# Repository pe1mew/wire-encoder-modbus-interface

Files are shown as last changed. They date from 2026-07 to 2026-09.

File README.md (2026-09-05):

# Wire Encoder Modbus Interface

A CH32V003-based interface board that measures **how far a window is open**
and publishes it on **Modbus RTU over RS-485**, powered by 24 V passive PoE
and designed for daisy-chained field buses.

The measurement comes from a **draw-wire encoder**: a spring-loaded drum
pays out a steel wire attached to the moving window frame, and the drum
turns a **10 kΩ potentiometer**. The wiper voltage is therefore an absolute
measure of the opening — valid the instant power returns, with no homing
move and no count to lose.

Two end-of-travel switches report that the window has reached a mechanical
stop, read as a supervised resistor ladder that also monitors its own cable.

One firmware build, addressed by a PC1 solder jumper:

| Jumper open | Jumper bridged |
|---|---|
| **40** | 45 |

The 40/45 pair is deliberately clear of the sibling
[`windmeters-modbus-interface`](https://github.com/pe1mew/windmeters-modbus-interface)
family (30–37), so both can share one RS-485 segment.

## Project status (2026-09-05)

| Area | State |
|---|---|
| Requirements | [`design/TDS.md`](design/TDS.md) **v0.7** — **79 requirements** (28 FR-MB, 20 FR-S, 23 FR-E, 8 NFR), every one traced to a test row and **gate-enforced** by `software/hil/acceptance/test_traceability.py` |
| Drivers | Modbus RTU + debug UART carried over HIL-verified; the encoder driver (`software/drivers/wire_encoder/`) is **written, verified and integrated** |
| Product firmware | **Complete.** Integration stages **A–F done** ([`design/integrationPlan.md`](design/integrationPlan.md)) — measurement, averaging, persistence and sensing health. 6 364 B flash (44 %), 1 108 B RAM (62 %). A healthy device reports status `0x0000` |
| Hardware/HIL | Schematic and PCB layout in `hardware/KiCad/`; the build under test is still a **breadboard**, so every Group A result carries that caveat. HIL rig complete: ADALM2000 RS-485 master, Saleae Logic16, and a built window emulator |
| Testing | 3 host suites (`scale`, `avg`, `health`), 27 HIL scripts, 11 acceptance tests. Results in [`software/hil/testReport.md`](software/hil/testReport.md) |
| Blocked | Four items, all on **instruments, not code**: adjustable PSU (±15 % supply margin, TP-A03/TP-B23 — the tightest unmeasured number), a PCB (TP-B36), a precision resistance box (FR-E03), a 5 ms bounce injector (FR-E15) |
| Release | No firmware version tagged yet; `fw-v1` is a candidate pending the above ([`software/firmware/RELEASES.md`](software/firmware/RELEASES.md)) |

## Hardware

The board reuses the sibling project's design wholesale apart from the
sensor front-end:

- **MCU**: WCH CH32V003J4M6 (RISC-V, SOP-8, 16 KB flash / 2 KB RAM). The
  8-pin package drives the whole design: single-wire UART discipline, remap
  tricks, and a zero-interrupt firmware architecture
  ([`design/softwareArchitecture.md`](design/softwareArchitecture.md)).
- **RS-485**: MAX3485; DI+RO tied to PD6, DE+R̄Ē tied to PC2 with a 10 k
  pull-down (keeps the bus safe during reset/flashing); 120 Ω terminator
  behind a solder jumper; A/B fail-safe bias; SM712 TVS.
- **Power**: 24 V passive PoE on the spare pairs (4/5 = +, 7/8 = −) →
  DB207 bridge (polarity protection only) → HLK-K7803 buck → 3.3 V.
- **Sensor front-end**: the potentiometer wiper on PA2 (ADC ch0), read
  ratiometrically against VDD — no external reference, so supply ripple
  cancels. The end-switch ladder is on PC4 (ADC ch2).

**The pin budget is the binding constraint.** The SOP-8 package bonds
several GPIO onto shared pins (pin 1 is PD6 *and* PA1; pin 8 is PD1, PD4
*and* PD5), leaving **six physical I/O pins — and every one is committed**:
Modbus data, the wiper, DE/RE, the address jumper, the end-switch ladder,
SWIO. Note PC1 and PC4 are assigned the reverse of the obvious way: PC4
carries an ADC channel and PC1 does not, so the analog pin goes to the
switch loop and the boot-time address jumper takes the digital pin. Any
front-end idea that needs another pin does not fit. See
[`design/TDS.md`](design/TDS.md) §4.2.

## Modbus register map (summary)

12 input registers (FC04) and 6 holding registers (FC03/06/16). Inputs:
instantaneous and averaged opening, the minimum/maximum of the current
averaging window, the raw ADC code, status bits (including end-of-travel
reached and switch-loop fault), identification (build + firmware version),
uptime, CRC/served counters, seconds-since-last-valid-reading, and movement
rate. Holdings: zero offset,
measurement window, averaging window, full travel, and the two-point raw
calibration (raw code closed / raw code fully open) — so one image serves
any window, calibrated in the field over Modbus. All persisted in flash
across reset/power-loss; the defaults apply only on first boot / erased
store. The authoritative map with ranges, defaults and requirement IDs is
[`design/TDS.md`](design/TDS.md) §2.7/§2.8.

## Repository layout

| Path | Contents |
|---|---|
| [`design/`](design/README.md) | The design-document chain (index in [`design/README.md`](design/README.md)): scratchBook → description → TDS → softwareArchitecture (+ UML diagrams in `design/diagrams/`) → driverDevelopment → integrationPlan |
| `hardware/KiCad/` | Schematic + PCB (KiCad); symbol libraries as git submodules |
| `hardware/Documentation/` | Component datasheets (HLK-K78xx, DB20x, MAX3483/85, Kradex enclosure) |
| `software/firmware/` | Product firmware (PlatformIO + ch32v003fun): one release build, plus a bench-only test build |
| `software/drivers/` | Standalone driver projects with HIL test shells (the verified libraries the product references in place) |
| `software/hil/` | Scripted hardware-in-the-loop harness: Saleae Logic 2 (MCP) + ADALM2000 (libm2k) + `acceptance/` pytest suite |
| `Doxyfile` | Doxygen config — builds a single site (design docs + API reference) with this README as the landing page |
| `documentation/` | Chip pinout, programmer manual, and sensor reference material |

Clone with submodules:

```sh
git clone --recurse-submodules https://github.com/pe1mew/wire-encoder-modbus-interface.git
```

## Building and flashing

Requires [PlatformIO](https://platformio.org/) and a WCH-LinkE on SWIO.

```sh
cd software/firmware
pio run                            # the release build
pio run -t upload                  # flash via WCH-LinkE
```

`encoder_test` adds bench-only hooks — never release that binary. Resource
ceilings (14 336 B flash / 1 792 B RAM, NFR-RES01) are enforced as hard
build gates.
The firmware version byte lives in `src/version.h`; the release process is
documented in `RELEASES.md`.

## Testing

- **Acceptance suite** (bench: Saleae Logic 2 with its MCP server, ADALM2000,
  WCH-LinkE, TTL Modbus rig):

  ```sh
  cd software/hil/acceptance
  ..\.venv-m2k\Scripts\python.exe -m pytest .
  ```

  Only the build-gate rows are populated so far; the protocol and
  measurement rows arrive with the driver work. See
  [`software/hil/README.md`](software/hil/README.md) for instrument setup,
  wiring, and the bench-quirk catalogue.

## Documentation

- **What the device does** — [`design/description.md`](design/description.md)
  is the functional description in prose: sensing principle, what it
  reports, commissioning, fault behaviour, and the boundary of what it does
  not do. Start there.
- **Design record** — [`design/README.md`](design/README.md) indexes the
  document chain (requirements → architecture → drivers → integration) and
  the UML diagrams.
- **API + design site** — the firmware headers/sources carry full Doxygen,
  and [`Doxyfile`](Doxyfile) folds the design docs in as pages with this
  README as the landing page. Build the browsable HTML with:

  ```sh
  doxygen Doxyfile        # output in documentation/doxygen/html/index.html
  ```

## Related repositories

- [`pe1mew/windmeters-modbus-interface`](https://github.com/pe1mew/windmeters-modbus-interface) —
  the sibling project this repository is derived from: same MCU, same
  RS-485 front-end, same zero-ISR architecture, and the same potentiometer
  reading topology. Its Modbus RTU driver, board/persistence modules and
  HIL harness are carried over here, and its `design/` chain is the
  reference for anything not yet written down.
- [`pe1mew/windmeters-modbus-interface-tester`](https://github.com/pe1mew/windmeters-modbus-interface-tester) —
  the Modbus RTU master bench tool (M5Stack AtomS3 + RS-485) used to
  exercise devices in this family.

## License

Software is provided under a Source-Available Non-Commercial License;
documentation and images under CC BY-NC-ND 4.0. See [LICENSE](LICENSE) and
[license.md](license.md). Third-party datasheets and KiCad library
submodules remain under their owners' terms.

## Author

Remko Welling (PE1MEW)

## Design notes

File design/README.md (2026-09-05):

# Design documentation

This directory holds the design record for the Wire Encoder Modbus
Interface firmware — the chain from first idea to a validated,
requirement-traced implementation. The documents build on each other in
this order:

```
scratchBook  →  description  →  TDS  →  softwareArchitecture  →  driverDevelopment  →  integrationPlan
(brainstorm)   (what it does)  (what   (how + diagrams)         (drivers + results)   (product fw + results)
                in prose)      must
                               be true)
```

## What the device does

Measures **how far a window is open** — a greenhouse vent, a roof light, a
louvre — and publishes it on Modbus RTU over RS-485. A draw-wire encoder
attached to the moving frame turns a **10 kΩ potentiometer**; the wiper
voltage is an absolute measure of the opening, valid the instant power
returns, with no homing move.

## Where this project stands

Read this before trusting a status line anywhere else: **the Modbus and
platform half of this project is inherited and proven; the measurement half
is a plan.** The documents below are honest about which is which, and the
distinction matters when you pick up the work.

| Document | Purpose | Status |
|---|---|---|
| [`description.md`](description.md) | **Functional description** — what the device does, in prose, for an integrator or installer: the sensing principle, what it reports, commissioning, fault behaviour, and what it deliberately does *not* do. Start here. | Current. The measurement path is implemented and verified; §3.1 documents the health bits and §8.1 the end-sensor and draw-wire installation rules |
| [`TDS.md`](TDS.md) | **Technical Design Specification** — the requirements contract (FR-MB…, FR-S…, FR-E…, NFR-…) with measurable pass/fail criteria. The single source of truth for behaviour. | **v0.7 draft.** §2 Modbus and §3.1/§3.2 lifecycle inherited from the sibling project's v0.9 and verified there; §2.7/§2.8 register map and the FR-E series are new and expected to move; §4 hardware open |
| [`softwareArchitecture.md`](softwareArchitecture.md) | **How** the requirements are met: the zero-ISR cooperative super-loop, the module split, the sizing rationale. §7 embeds the UML diagrams. | Current. All modules are in the tree and verified; §5 carries the as-built sizes and the **1.146 ms blocking budget** |
| [`driverDevelopment.md`](driverDevelopment.md) | Plan + results per standalone driver, each HIL-verified before integration. | All phases satisfied. Phase 1 (the encoder driver) is written, HIL-verified and integrated; its acceptance rows close through integration stages D–E |
| [`testPlan.md`](testPlan.md) | **Hardware test plan** — every row traced to a TDS verification clause, grouped by what the current image can actually exercise: electrical (no firmware), protocol and lifecycle, and what stays blocked until integration stage D. | **v0.3.** Groups B and C executed and passing; Group A partly blocked on an adjustable PSU and a PCB. Every requirement is gate-checked for a test row by `test_traceability.py` |
| [`integrationPlan.md`](integrationPlan.md) | The product-firmware plan: stages A–F, each with an exit criterion, plus the hardware-gated test set. | **Stages A–F all complete.** Remaining work is blocked on instruments, not code |
| [`scratchBook.md`](scratchBook.md) | The brainstorm and working notes seeding the TDS — the sensor, the pin budget, scaling derivation, resolution/range decision, hardware questions. | Working notes |
| [`windowEmulator.md`](windowEmulator.md) | **Window and window-controller emulator** — a bench rig standing in for a window and its actuator controller: the control logic and its truth table, plus the mechanical and safety requirements. Scoped to the rig alone; it specifies nothing about what is mounted on it. | **v0.4 — built and in bench service.** Closed seven FR-E/EM rows. §1.1 records two as-built traits that change how results read |
| [`requirementsCompliance.md`](requirementsCompliance.md) | Compliance check against the `greenhouse-Controller` M3 window-position-sensor requirements study — a matrix of that document's FR-WP/NF-WP requirements against this design, with the gaps. | Analysis only; the source study is itself marked *not adopted*. **FR-WP07 is flagged conditional** — bit 3 reports the sensor, not the window |
| [`diagrams/`](diagrams/) | UML diagrams as PlantUML sources + rendered PNGs, plus the window-emulator controller schematic (see below). | — |
| [`../docs/modbusInterfaceContractSpecification.md`](../docs/modbusInterfaceContractSpecification.md) | **Interface contract for the client** — the greenhouse controller's view: where each value lives, what it means and does *not* mean, how to teach, which bits are alarms and which are health. Organised by purpose, every statement traced to a TDS requirement. §8 sizes the configuration to the target window (1.5 m in 171 s, the M3 travel time) and gives the study's FR-WP20 threshold — which turns out to be that window's nominal speed — the margin it needs. | **v1.2.** Derived from TDS v0.7; the TDS stays normative. Not a design input — a design *output* for the other side of the bus |

## The constraint that shapes everything

The CH32V003**J4M6** is the SOP-8 package, and several GPIO share one
physical pin (pin 1 is PD6 *and* PA1; pin 8 is PD1, PD4 *and* PD5). There
are **six physical I/O pins and every one is committed**: Modbus data, the
potentiometer wiper (ADC ch0), RS-485 DE/RE, the address jumper, the
end-switch ladder (ADC ch2), and SWIO. Check any front-end proposal against
TDS §4.2 before assuming a pin exists.

Note the PC1/PC4 assignment is the reverse of the obvious one: **PC4 has an
ADC channel and PC1 does not**, so the analog pin goes to the switch loop
(which has more than one bit to say) and the boot-time address jumper takes
the digital pin.

## Diagrams

Three UML views live in [`diagrams/`](diagrams/) and are embedded in
[`softwareArchitecture.md`](softwareArchitecture.md) §7:

- **[`component.puml`](diagrams/component.puml)** — module structure & data
  flow (potentiometer → `we` → `meas_open` → `regs` hub → Modbus). Planned
  modules are shaded.
- **[`superloop_sequence.puml`](diagrams/superloop_sequence.puml)** — one
  zero-ISR super-loop iteration.
- **[`windowEmulatorController.py`](diagrams/windowEmulatorController.py)** —
  not UML: the window-emulator controller schematic, rendered to
  `windowEmulatorController.png` by running the script. Embedded in
  [`windowEmulator.md`](windowEmulator.md) §3.
- **[`modbus_state.puml`](diagrams/modbus_state.puml)** — the Modbus RTU
  line-discipline state machine, carried over unchanged from the sibling
  project (the protocol behaviour is identical).

Regenerate the PNGs with the local PlantUML:

```sh
"C:/apps/plantuml/plantuml.exe" -tpng -o . design/diagrams/*.puml
```

## Build configuration

**One release build** (FR-S01) — there is one sensor read one way, so there
is no variant machinery. It is addressed by a **PC1** solder jumper:

| Jumper | Address |
|---|---|
| open | **40** |
| bridged | 45 |

Deliberately clear of the sibling windmeters family (30–37) so both can
share one RS-485 segment. One non-product environment sits beside the
release build: `encoder_test` (bench-only hooks — never released).

## How this connects to the rest of the repo

- The **API reference** ([`Doxyfile`](../Doxyfile) at the repo root) folds
  these design documents in as pages alongside the header/source
  documentation — run `doxygen Doxyfile` for a single browsable site with
  the project [`README.md`](../README.md) as its landing page.
- The requirements here are verified by the scripted bench in
  [`software/hil/`](../software/hil/); every executed test with its
  setup/expected/verdict belongs in
  [`software/hil/testReport.md`](../software/hil/testReport.md).
- Contribution workflow (requirements-first, build, run the acceptance
  suite) is in [`contributing.md`](../contributing.md).
- **The sibling project is part of the design record.** Where this chain
  says "inherited", the reasoning and the bench evidence live in
  [`windmeters-modbus-interface`](https://github.com/pe1mew/windmeters-modbus-interface)'s
  `design/` directory. Don't re-derive what is already written down there —
  in particular, its vane driver is the reference implementation for
  reading a potentiometer on PA2.

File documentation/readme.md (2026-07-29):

# Contents

| File | What it is |
|---|---|
| `CH32V003.pdf`, `CH32V003RM.PDF` | WCH CH32V003 datasheet and reference manual |
| `CH32V003J4M6-Pinout.jpg` | **Pinout of the SOP-8 package.** Worth looking at before proposing any front-end change: pin 1 carries PD6 *and* PA1, pin 8 carries PD1, PD4 *and* PD5, so there are six physical I/O pins, not seven (TDS §4.2) |
| `WCH-LinkUserManual.PDF` | WCH-LinkE programmer manual |
| `Proximity-Switch-LJ18A3-8-Z-BX.pdf` | **The selected part.** Full spec table: 6–36 V (12–24 V nominal), <13 mA consumption, <300 mA output, 8 mm ±10 % against 30 × 30 × 1 mm iron, <10 % hysteresis, 500 Hz, −30…+65 °C, reverse-connection + surge + short-circuit protection, nickel-plated brass body with ABS sensing face |
| `LJ_en.pdf` | **Finglai LJ-series manual — the authoritative document.** Model decoder (`Z/BX` = NPN NO 6–36 V, `Z/BX-5V` = NPN NO 5 V, `Z/BY` = PNP NO), safety notes, and — most importantly — the **internal output circuit diagrams**, which show a 10 kΩ pull-up from the output to +V inside the NPN part. See the warning below |
| `5911600_lj18a3.pdf` | LJ18A3 family **selection chart** (Yueqing Hengwei) — confirms the model coding and the M18×1 outline drawing. No electrical parameters |
| `14_PROXIMITY_INDUCTIVE_18BY.pdf` | ⚠️ **This is the LJ18A3-8-Z/BY — the PNP variant, not the part we use.** Its page 2 model table covers the whole family (including our /BX) and its outline drawing is right, but **its specification table is for a PNP output.** See the warning below |
| `S9b9323826f2e48bca2893117435ce239v.pdf` | Mann Hwa / Zhongyang **ZY-series encoder catalogue** — see the warning below |
| [`product-images/`](product-images/readme.md) | Supplier photographs for both sensors, renamed and indexed. **Three of them carry specification data found nowhere else** — including the draw-wire unit's only spec table (0.2 % error, >100 000 cycles, **IP50**) and the drawing that identifies the exact variant to order. Start at its [readme](product-images/readme.md) |

> ⚠️ **The NPN output is not a bare open collector.** `LJ_en.pdf` page 2 shows
> an **internal 10 kΩ pull-up from the output (black) to +V (brown)** inside
> the sensor. Powered at 24 V, the output therefore *sources* roughly 2 mA at
> 24 V when no target is present — it does not simply float. Any interface
> that assumes an open collector and pulls the line up to 3.3 V will be driven
> well above the rail. Verify on the actual part before wiring: with the sensor
> unpowered, measure brown-to-black; ~10 kΩ confirms the internal pull-up.

> ⚠️ **`14_PROXIMITY_INDUCTIVE_18BY.pdf` describes the PNP variant.** The
> suffix is the giveaway: **/BX = NPN** (what we use), **/BY = PNP**. The two
> are otherwise near-identical in size, range and supply, so the documents look
> interchangeable and are not.
>
> This matters more than a documentation nit. The board pulls PC4 up to 3.3 V
> and relies on the sensor **sinking** it — safe, because an open-collector
> output sources nothing. A PNP part *sources* its supply rail instead, so
> wiring one in would put **24 V onto an ADC pin** and destroy it. Check the
> suffix on the actual sensor before connecting anything, not the datasheet
> that came with it.

> ⚠️ **The ZY-series catalogue does not describe the sensor this project
> uses.** It is a generic multi-model catalogue of **incremental** rotary
> encoders (A/B quadrature, optional Z index; NPN/PNP/push-pull/line-driver
> output stages; 10–3000 P/R), covering ZY2504, ZY3806, ZY3808B, ZY4006,
> ZY5006 and the ZY7 handwheel series. Its "本体 Absolute rotary encoders"
> section heading is a mistranslation — 本体 means "main body", not
> "absolute" — and every model decoder underneath reads
> "C: 增量式编码器 Incremental Rotary Encoder".
>
> The unit this project uses is a **draw-wire encoder with a 10 kΩ
> potentiometer** (TDS §1.1, §3.4): absolute, analog, read on one ADC pin.
> Keep the catalogue for reference if you like, but do not design against
> it.

# WCH MCU documentation on the web

 - https://github.com/limingjie/WCH-MCU-Pinouts/tree/main

# Source downloaded PDF

 - https://www.olimex.com/Products/RISC-V/WCH/WCH-LinkE/resources/WCH-LinkUserManual.PDF
 
# Wiring WCH-Link 

## to nanoCH32V003

```
        nanoCH32V003             WCH-LinkE
      +--------------+    +----------------+
      |              |    |                |
      |          GND o----o GND            |
      |          DI0 o----o SWDIO/TMS      |
      |          VCC o----o 3V3            |
      |              |    |                |
      +--------------+    +----------------+
```

## CH32V003 J4M6 D03

You need a WCH-LinkE programmer to flash this MCU. You connect SWIO to PD1 (pin 8), VDD to pin 4 and VSS to pin 2.

```
     CH32V003J4M6D03             WCH-LinkE
   +-----------------+    +----------------+
   |                 |    |                |
   |         VSS (2) o----o GND            |
   |         PD1 (8) o----o SWDIO/TMS      |
   |         VDD (4) o----o 3V3            |
   |                 |    |                |
   +-----------------+    +----------------+
```

# Platformio an the WCH CH32V Platform

 - https://ch405labs.net/ch32v003_intro/

# The draw-wire sensor (supplier description)

Supplier copy for the pull-rope displacement sensor, kept verbatim below. Two
points from it matter to the design and are worth pulling out first:

- **Output options are 4–20 mA, 0–5 V, 0–10 V, or 10 kΩ resistance.** This
  project uses the **10 kΩ resistance** variant — a bare potentiometer, which
  is what makes the measurement passive, absolute and ratiometric (TDS §3.4,
  §4.3). The three active outputs would all need their own supply and would
  break the ratiometric cancellation; do not substitute one.
- **Lengths: 1 m, 1.5 m, 2 m.** The greenhouse M3 flap travels ~2 m, so the
  2 m variant is the one to order — and TDS §6's note about matching the
  register resolution to the wire length is satisfied: 2 m is well inside the
  6.5 m the 0.1 mm register range allows.

The "5–24 V DC input power supply" in the copy below applies to the
active-output variants. A 10 kΩ resistance output is passive and takes no
supply of its own; this board feeds it from its own 3.3 V rail so that the
divider and the ADC reference are the same rail.

---

Precision displacement measurement with multiple output options The pull rope displacement sensor offers accurate distance measurement with various output types including 4-20mA, 0-5V, 0-10V, and 10kΩ resistance, ensuring compatibility with diverse industrial systems.

Flexible range options for different applications Available in three lengths: 1M, 1.5M, and 2M, this sensor supports a wide range of displacement needs, making it ideal for automation, machinery, and monitoring systems requiring precise positioning.

Wide input voltage compatibility Designed for stable operation with an input power supply of 5–24V DC, this sensor ensures reliable performance across various electrical environments without voltage fluctuations.

Durable alloy construction for long-term use Made from high-quality alloy material, the sensor resists wear and environmental stress, providing long-term durability in industrial and mechanical applications.

CE certified for safety and compliance Certified with CE, this sensor meets European safety and electromagnetic compatibility standards, ensuring reliable and compliant operation in regulated environments.

Compact and lightweight for easy integration With a package size of 10 x 10 x 7 cm and a weight of 0.550 kg, it is easy to install and integrate into tight spaces without adding bulk to existing systems.

One piece per pack, simple and efficient Sold as 1 piece per pack, this sensor is ideal for direct replacement, spare parts, or small-scale projects, offering convenience and cost-efficiency for users.

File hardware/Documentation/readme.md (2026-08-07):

# Component datasheets

Datasheets for the bought-in parts of the board and its installation. The
sensors' own documentation lives in [`documentation/`](../../documentation/)
alongside the MCU reference material.

| File | Part | Used for |
|---|---|---|
| `99966478_nl_td.pdf` | **Kopp 99966478 enclosure** — IP65 junction box, 110 × 110 × 40 mm (50 mm deep), black, halogen-free, screwed lid, 6 cable entries with **3 × M20 glands supplied** | The device enclosure (TDS §4.5). See the two notes below |
| `MAX3483-MAX3491.pdf` | Maxim MAX3485 | RS-485 transceiver (TDS §4.1) |
| `006548_HLK-K78xx-500R3_Datasheet.pdf` | Hi-Link HLK-K7803-500R3 | 24 V → 3.3 V buck regulator (TDS §4.1) |
| `db201-db207.pdf` | Rectron DB207 | Bridge rectifier, used for reverse-polarity protection only (TDS §4.1) |
| `003223_Kradex_Z57JPH_TM_ABS.pdf` | Kradex Z57JPH ABS | **Inherited from the sibling project — superseded** by the Kopp box above. Kept because it is referenced by the windmeters design this project was bootstrapped from |

## Two things about the enclosure

**It is IP65, and that is now what TDS NFR-ENV03 asks for.** The requirement
originally said IP67; it was narrowed on 2026-07-29 to match this box, with
the box named as what sets the figure — the same treatment the temperature
ceiling got from the end-switch sensor. The greenhouse study asks "IP65
minimum, IP67 preferred", and its preference for IP67 was written for hardware
*at the aperture, which may be rain-wetted with the vent open*. This box holds
the electronics and is mounted inside the structure, so it meets the level
that applies to it. The genuinely exposed part is the draw-wire unit, which is
IP50 — that gap is live and tracked in `design/requirementsCompliance.md` §4.

**Count the cable entries before ordering.** Six are available; three M20
glands are supplied. The installation needs:

| Entry | For |
|---|---|
| 1 | RS-485 bus in |
| 2 | RS-485 bus out (daisy chain, TDS §4.1) |
| 3 | Draw-wire sensor |
| 4 | End switch A |
| 5 | End switch B |
| 6 | Pressure-equalisation vent plug (TDS §4.5) |

That is **all six entries used, with three more glands plus the vent to buy
and nothing spare.** Two things make this tighter than it looks: the vent
occupies an entry, which is easy to overlook when a box is specified by cable
count alone; and the **star topology** (TDS §4.4, decided 2026-08-07) gives
each end switch its own run to the hub instead of summing them in a field
junction, which costs the sixth entry. If anything else ever has to enter this
box, it needs a different box.

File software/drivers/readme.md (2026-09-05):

# Drivers for CH32V003J4M6

Standalone driver projects, each with its own HIL test shell. The product
firmware in [`../firmware/`](../firmware/) references these libraries **in
place** through `lib_extra_dirs` — nothing is copied, so the code that ships
is the code that was tested.

The development method (build standalone → verify every matrix row on
silicon → only then integrate) is in
[`design/driverDevelopment.md`](../../design/driverDevelopment.md).

| Project | Deliverable | Status |
|---|---|---|
| [`blinky_template/`](blinky_template/) | Bare-MCU bring-up: board, framework and WCH-LinkE upload settings. The starting point when cloning a new driver project. | Inherited, verified |
| [`common/debug_uart/`](common/debug_uart/) | `dbg_*` — TX-only trace UART on PD6, 115200 8N1. Driver-phase tool only; never linked into a release binary. | Inherited, verified |
| [`modbus_rtu/`](modbus_rtu/) | `mb_*` — the Modbus RTU slave driver: framing, CRC, t3.5 gap detection, FC03/04/06/16, exceptions, DE control. | Inherited, verified (26/26 matrix + 40/40 endurance in the source project) |
| [`wire_encoder/`](wire_encoder/) | `we_*` — absolute window-opening readout: 10 kΩ potentiometer on PA2, ratiometric 10-bit ADC, plus the end-switch ladder on PC4. | **Written and HIL-verified** (2026-09-01), integrated at stage D. Note its ADC sample time is **≥241 cycles**, not the sibling project's ≥71 — FR-E21's series resistor changes the source impedance. See the project README |

**"Inherited" means carried over from the sibling
[`windmeters-modbus-interface`](https://github.com/pe1mew/windmeters-modbus-interface)
project**, where each was HIL-verified on this same MCU. The evidence lives
in that repository's `software/hil/testReport.md`. It has not been re-run on
this project's hardware — there is no hardware yet.

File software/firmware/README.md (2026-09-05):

# Firmware — Wire Encoder Modbus interface

PlatformIO project for the **CH32V003J4M6** (RISC-V, SOIC-8, 16 KB flash /
2 KB RAM). Measures window opening from a draw-wire encoder's 10 kΩ
potentiometer, read ratiometrically on PA2, and publishes it over Modbus
RTU (TDS §1.1, §3.4).

> **Status: complete and HIL-verified.** Integration stages **A–F are done**
> ([`design/integrationPlan.md`](../../design/integrationPlan.md)): board
> bring-up, the register image, flash persistence, the ADC driver, the
> measurement service, averaging, and the FR-E23/FR-E24 sensing-health checks.
> A flashed device measures, publishes, and reports status **`0x0000`** when
> healthy. Executed evidence is in
> [`software/hil/testReport.md`](../hil/testReport.md).
>
> What is **not** closed is blocked on instruments, not on code: FR-E03 needs a
> precision resistance box at five ratios, FR-E15 a 5 ms bounce injector, and
> TP-A03/TP-B23 an adjustable PSU — that last one covers the ±15 % supply
> margin, the tightest unmeasured number in the design.

## Modules

| File | Responsibility |
|---|---|
| `main.c` | The zero-ISR super-loop. **Nothing here may block for more than ~1 ms** — see the budget below |
| `board.c` | Clocks, GPIO, the FR-S18 bring-up order |
| `regs.c` | The register image, FC dispatch, status-bit assembly |
| `persist.c` | Flash-backed holdings (FR-S39), 20-byte `rec_t` |
| `meas_open.c` | Measurement pacing at 40 Hz; wiper and switch ladder on **alternate ticks** |
| `scale.c` | FR-E04 two-point opening scale, sign-aware, clamped |
| `avg.c` | FR-S31 two-stage boxcar (mean/min/max), ~384 B |
| `health.c` | FR-E23 position-not-following, FR-E24 plausible band |
| `version.h` | `FW_VERSION` — the single source for register 30007 |

The ADC driver itself lives outside this project, in
[`software/drivers/wire_encoder/`](../drivers/wire_encoder/), and is referenced
in place.

## ⚠ The blocking budget

No requirement states this, and it has bitten the project once:

> `mb_rx_service` polls a single-byte USART register. Any main-loop pass longer
> than **one character time (1.146 ms at 9600 baud)** loses a byte to overrun,
> and FR-MB24 discards the frame — **without** incrementing 30009, because an
> overrun is not a CRC error. Requests vanish with no diagnostic anywhere.

Integration stage D dropped **9.7 %** of requests before this was understood.
If you add work to the loop, measure the **pass time**, not just the
measurement-window budget.

Authoritative references: the register map and behaviour contract live in
[`design/TDS.md`](../../design/TDS.md) (§2.7 input / §2.8 holding registers,
§4.2 pin map); the zero-ISR super-loop design and module split in
[`design/softwareArchitecture.md`](../../design/softwareArchitecture.md).

## Build environments

**One release build.** There is one sensor read one way, so there is no
variant machinery and no `SENSOR_*` selector.

| Environment | Extra define | Purpose | Release? |
|---|---|---|---|
| `encoder` | — | **The product.** Build byte 0x01, address 40 (PC1 jumper open) / 45 (bridged) | ✅ |
| `encoder_test` | `TEST_HOOKS` | FR-S20 watchdog hang trigger (holding `0x00FF`, magic `0xDEAD`) for the HIL reset checks | ❌ **never** |

The end-of-travel switches are **not** an option: they are read as a
supervised resistor ladder on PC4 (TDS §4.4) and are part of the product.

## Prerequisites

- [PlatformIO Core](https://platformio.org/install/cli) (`pip install platformio`)
  or the PlatformIO VS Code extension.
- A **WCH-LinkE** programmer on SWIO (PD1).

The community WCH platform (`platform = ch32v`) and the `ch32v003fun`
framework are pulled automatically on first build. The verified driver
libraries (`mb_*`, `dbg_*`) are referenced **in place** from
[`software/drivers/`](../drivers/) — no copies.
`software/drivers/wire_encoder/lib` is on `lib_extra_dirs` as of stage D; the
linker pulls `we.c` in because `meas_open.c` includes `we.h`.

## Usage

```sh
pio run                            # the release build
pio run -t upload                  # flash via WCH-LinkE
```

There is no serial console: the release firmware never transmits
unsolicited (FR-S19) — PD6 is the Modbus data line. Talk to a flashed
device over RS-485/Modbus RTU (9600 8N1).

## Resource ceilings (NFR-RES01)

The 87.5 % ceilings — **14 336 B flash / 1 792 B RAM** — are hard build
gates (`board_upload.maximum_size` / `maximum_ram_size`); a build that
exceeds them fails. As-built:

| Environment | Flash | RAM |
|---|---|---|
| `encoder` | 6 364 B (44.4 %) | 1 108 B (61.8 %) |
| `encoder_test` | 6 396 B (44.6 %) | 1 112 B (62.1 %) |

**As-built with stages A–F complete** (measured 2026-09-05), so these are a
planning basis. RAM is the tighter of the two: `avg.c`'s ring accounts for
~384 B of the 1 108 B, and the remaining headroom is ~684 B.

## Configuration and calibration

All six holding registers (40001–40006) are runtime-writable and **persist
in flash across reset/power-loss** (FR-S39). Opening scaling is a two-point
runtime calibration (FR-E05), so one binary serves any window with no
rebuild. **Calibration is a field procedure over Modbus:**

1. Close the window fully. Read 30005 (raw ADC) and write that value to
   **40005**.
2. Open it fully. Read 30005 and write that value to **40006**.
3. Measure the actual travel and write it, in 0.1 mm, to **40004**.

The order does not matter and neither does the direction: if the raw value
*falls* as the window opens, write the readings to the same registers anyway
— 40005 is whatever you read with the window closed, 40006 whatever you read
with it open. The firmware handles both senses (FR-E04). The two must differ
by at least 64 counts (FR-E06).

**Size the draw-wire so neither end sits at an electrical extreme.** Leave
≥10 % of ADC range beyond each end of travel (`design/description.md` §8.1).
This is not tidiness: if fully-closed reads near 0, a conductor shorted to
ground is *indistinguishable* from a correctly closed window, and no firmware
can separate them. The headroom is also what makes FR-E24's plausible band
meaningful — on a rig that traverses the full 0–1023 the band covers every
reachable code and the check is inert by design.

That's it — the values survive power loss. The compile-time defaults that
seed those registers on first boot can be overridden per build:

```ini
build_flags = ... -D RAW_CLOSED_DEFAULT=0 -D RAW_OPEN_DEFAULT=1023
```

`RAW_OPEN_DEFAULT` otherwise follows `WE_RAW_MAX_DEFAULT` in `sensors.h`
(1023, the 10-bit ADC full scale). **Keep it equal to the driver's
`we_raw_max()`** — a mismatch calibrates a fresh device to nonsense on first
boot and nothing in the FR-E04 scaling can detect it.

## Versioning and releases

The firmware version byte (reported in input register 30007, low byte) has
a single source: [`src/version.h`](src/version.h). Releases are registered
in [`RELEASES.md`](RELEASES.md). The old bar for `fw-v1` — "not until the
measurement service exists" — **has been met**; the remaining question is
whether to release with FR-E03 and FR-E15 still open on instrument
availability. That is a release decision, not a code one.

## Testing

- **Host tests** (no hardware). Three suites, each compiling the **shipped**
  source rather than a copy. MinGW ships with Code::Blocks on this bench:

  ```sh
  cd test
  gcc -O2 -Wall -Wextra -I../src -o test_scale  test_scale.c  ../src/scale.c  && ./test_scale
  gcc -O2 -Wall -Wextra -I../src -o test_avg    test_avg.c    ../src/avg.c    && ./test_avg
  gcc -O2 -Wall -Wextra -I../src -o test_health test_health.c ../src/health.c && ./test_health
  ```

  `test_avg` (26 checks) pins FR-S31's block **min/max** — a block *mean* makes
  the envelope wrong in a way that still looks plausible. `test_health`
  (25 checks) pins the two properties easiest to break silently: FR-E24 must be
  **self-disabling** on a full-range calibration, and FR-E23 must not count a
  window **rocking on its stop** as a departure.

  The FR-E04 opening scaling is pure integer
  arithmetic with a sign-aware map, clamping at both ends and 0.0046 % of
  overflow headroom — so it lives in `src/scale.c` with no hardware
  dependency, and the test compiles the shipped code:

  ```sh
  cd test
  gcc -O2 -Wall -Wextra -I../src -o test_scale test_scale.c ../src/scale.c && ./test_scale
  ```

  Covers both mounting senses, the offset behaviour at and beyond each
  calibration point, the overflow corners, the minimum legal calibration
  span, the unreachability of the fault sentinel, and monotonicity swept
  across the whole ADC range. Run it after touching anything in `scale.c`.

- **Acceptance suite** (bench):

  ```sh
  cd ../hil/acceptance
  ..\.venv-m2k\Scripts\python.exe -m pytest .
  ```

  **11 tests**, of which 7 need no hardware; the other 4 skip cleanly without
  an ADALM2000. Build gates, protocol checks, and the traceability gates that
  fail if any requirement gains no test row, if a row cites an id that does not
  exist, or if an id is abbreviated. Instrument setup, wiring
  and the bench-quirk catalogue are in
  [`software/hil/README.md`](../hil/README.md); executed HIL tests belong
  in [`software/hil/testReport.md`](../hil/testReport.md).

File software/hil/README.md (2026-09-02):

# HIL test harness

Scripted hardware-in-the-loop testing per `design/driverDevelopment.md`:
flash (`pio`) → stimulate (ADALM2000 / libm2k) → observe (Saleae Logic 2 MCP)
→ assert (Python).

> **Status: scaffolding.** The instrument-generic scripts below are carried
> over from the sibling
> [`windmeters-modbus-interface`](https://github.com/pe1mew/windmeters-modbus-interface)
> project and work as-is. The encoder and register-map check scripts do not
> exist yet, and **nothing here has been run against this project's
> hardware** — there is none. Every quirk catalogued below is inherited
> knowledge: re-confirm the wiring and channel mapping before trusting a
> capture.

> **Consolidated results:** [`testReport.md`](testReport.md) is the single
> record of every HIL test with its setup, expected result, pass criteria,
> and verdict. This README covers *how* to run the harness (instruments,
> wiring, quirks); the test report covers *what was tested and the outcome*.

## Instruments

| Instrument | Interface | Role |
|---|---|---|
| Saleae Logic16 (classic, digital-only) | Logic 2 built-in MCP server, `http://127.0.0.1:10530/mcp` (JSON-RPC/HTTP) | Observer: digital captures, protocol analyzers, CSV export |
| ADALM2000 (M2K) | libm2k (Python 3.11 venv) | Stimulus: pulse trains, bursts, DC levels/ramps, programmable supply; its scope verifies analog |
| WCH-LinkE | `pio run -t upload` (`%USERPROFILE%\.platformio\penv\Scripts\pio.exe`) | Flash + 3.3 V DUT power + UART monitor RX |

## Python environments

- Saleae scripts are **stdlib-only** — any Python ≥3.10 works.
- libm2k wheels top out at **cp311**, and the wheel alone is not enough —
  it needs the system-installed libm2k/libiio DLLs. Setup (one-time):
  1. Run `PlutoSDR-M2k-USB-Drivers.exe` (admin) — IIO/RNDIS USB drivers.
  2. Run `libm2k-0.9.0-Windows-setup.exe` (admin) — runtime DLLs.
  3. `python3.11 -m venv .venv-m2k` and
     `.venv-m2k\Scripts\pip install libm2k-0.9.0-cp311-cp311-win_amd64.whl`
     (wheel from the libm2k GitHub release `python-wheels.zip`).

## Scripts

| Script | Purpose | Status |
|---|---|---|
| `smoke_test.py` | Saleae MCP link: devices, capture, export | inherited, PASS in source project |
| `blinky_check.py` | Flash→capture→assert chain on the DUT (blinky timing) | inherited, PASS in source project |
| `uart_check.py` | debug_uart exit criterion (async-serial decode) | inherited, PASS in source project |
| `m2k_smoke.py` | M2K reachable, calibrated, subsystems up | inherited, PASS in source project |
| `m2k_signal_check.py` | Generate + verify each driver-phase stimulus signal | inherited, PASS in source project |
| `saleae_serial.py` | Shared module: UART capture + timestamped line decode | library |
| `modbus_rtu_codec.py` | Modbus RTU framing, CRC-16 and the 8N1 bit codec — **pure Python, no instrument** | library, **20/20 host tests pass** |
| `test_modbus_rtu_codec.py` | Host tests for the above: CRC vs an independent implementation over 2000 vectors, the published `01 03 00 00 00 0A` → `C5 CD` vector, byte order, exception decoding, UART round-trips | `python software/hil/test_modbus_rtu_codec.py` |
| `m2k_master.py` | **Raw RS-485 Modbus master** bit-banged from M2K DIO through a second MAX3485. `--selftest` for the static DE/DI proof | **run against the DUT 2026-09-01** — link up, 1000-poll latency measured |
| `group_b.py` | **Group B protocol matrix** (TDS §2) — 21 rows, 34 checks. Reads holdings as-found and restores them atomically in a `finally`, with a crash-safe stash for a killed run | **PASS** 2026-09-01 |
| `group_c.py` | **Group C measurement matrix** — FR-E04 scaling driven by the calibration against a fixed wiper, both mounting senses, both clamps; FR-S24, FR-E05, FR-E09, FR-E20 | **11/11 PASS** 2026-09-01 |
| `stage_d.py` | FR-E02 publish cadence, FR-E03 stability, FR-S30 window abort | **6/6 PASS** 2026-09-01 |
| `fr_e07.py` | FR-E07 wiper fault machine, both directions. Times the hold from 30011, because the hold is invisible in 30001 by design | **PASS** 2026-09-01 |
| `fr_e14.py` | FR-E14/E16 end-switch classification, all three §4.4.3 states, plus the opening-path isolation check | **PASS** 2026-09-01 |
| `tp_b20.py` | FR-S39 torn-write test — power cut during a burst of flash writes | **ACCEPTED at 13/20 cycles** 2026-09-01 |
| `tp_b21_b22.py` | FR-S20 watchdog recovery and FR-S21 post-reset state. **Needs the `encoder_test` build** | **PASS** 2026-09-01 |
| `tp_b24.py` | FR-S19 no-boot-banner — listens across a power cycle with the master released | **PASS** 2026-09-01 |
| `tp_b32.py` | FR-MB04 DE timing, measured from the bus drive envelope rather than a probe on PC2 | **PASS** 2026-09-01 |
| `tp_b33_b34.py` | FR-MB28 quantity limits and FR-MB24 malformed-frame handling | **PASS** 2026-09-01 |
| `tp_b35.py` | FR-S16/FR-MB23 soak and the FR-MB20/21 latency histogram | **PASS** 10 000 cycles 2026-09-01 |
| `movement.py` | Window-emulator movement rows — FR-E10 tracking, FR-E17 update age while moving, FR-E18/E19 direction and travel | **4/4 PASS** 2026-09-01 |
| `teach.py` | FR-E18/FR-E19 teach handshake end to end, both limits, including the refusal paths | **7/7 PASS** 2026-09-01 |
| `fr_e01.py` | FR-E01 opening in mm against the rig scale at 1000 mm | **PASS** 2026-09-01 |
| `em_m05.py` | Emulator EM-M05 — end-stop sensor still active at the mechanical limit, which **EM-M03 requires**. See the gotcha log: this was wrongly called a rig defect first | **PASS** 2026-09-01 |
| `tp_c01.py` | **FR-E23** position-not-following, status bit 7. Operator detaches the draw-wire and traverses; three departure sequences set the bit, one good one clears it | **PASS** 2026-09-01 |
| `tp_c02.py` | **FR-E24** plausible band, status bit 6. Moves the *band* rather than the carriage, so the calibration is the only variable. Also proves the factory default is inert | **5/5 PASS** 2026-09-01 |
| `power_cycle.py` | TP-B02/B04/B19 helper: arm → operator cycles power → check | **PASS** 2026-09-01 |

**First job when a board exists:** run `smoke_test.py`, then
`blinky_check.py` and `uart_check.py`. That is the ten-minute proof that
the rig is wired correctly, before any real work rests on a capture.

## Bench wiring notes

*Inherited — the channel numbers below describe the source project's bench
and are a starting point, not a fact about yours.*

- Saleae Logic16 lead labels ≠ channel indices (two 8-lead banks). After
  rewiring, locate signals with an all-channel sweep capture first.
- Keep M2K AWG outputs configured 0–3.3 V near the DUT (hardware can swing
  ±5 V — beyond CH32V003 absolute maximums).
- All grounds common (M2K, Saleae, LinkE, DUT).
- **MAX3485 rig**: DUT transceiver DI+RO → PD6, DE+R̄Ē → PC2 with the 10 k
  pull-down; bus A/B → M2K scope 1+/2+ for the analog wire view. A **second
  MAX3485 as raw master**: M2K DIO0 → DI, DIO1 → DE+R̄Ē, **V+ → VCC
  (3.3 V)** — every raw-master script must enable V+ itself
  (`ps.enableChannel(0, True)` + `pushChannel(0, 3.3)`): an unpowered
  MAX3485 sits inert, and the static DE/DI test (drive space, drive mark,
  release) is the 10-second wiring proof.

## RS-485 rig lessons (inherited, learned the hard way)

- **A listening master never stops buffering.** A Modbus master that only
  drains its UART during its own transactions buffers every byte another
  node puts on the shared bus, then parses the stale backlog and reports
  CRC_ERR. One throwaway read IS the flush — retry once on `crc_error`
  before trusting a read that follows raw-master traffic.
- **Inter-frame marks in composed patterns must exceed t3.5 (4.01 ms).**
  A 2.5 ms gap between a garbage tail and a recovery request made the DUT
  (correctly) coalesce them into one discarded frame — 48 bit times of mark
  (5 ms) is the house gap.
- **Noise floods don't move the DUT's CRC counter** — random bytes arrive
  framing-poisoned (FE/overflow) and take the silent-discard path; only
  cleanly-framed-wrong-CRC frames increment 30009. Assert flood recovery by
  behaviour, not by that counter.
- The DUT answers master baud offsets to ±3 % in both directions; its own
  HSI adds ~+0.3 %.

## M2K / libm2k quirks (inherited; fw v0.33 + libm2k 0.9.0)

- **Firmware ≥0.32 is mandatory** for libm2k 0.9.0 (shipped fw v0.27 gave
  erratic AWG output and version errors). Update: copy `m2k.frm` from the
  m2k-fw release onto the M2K mass-storage drive and eject; it self-flashes
  (~1 min, don't unplug).
- **Analog-out session-state corruption**: within one context, repeated
  output reconfiguration misbehaves — `stop()` wedges the DAC until
  `reset()`; a second cyclic `push()` at the same sample rate is silently
  ignored; non-cyclic pushes and `setVoltage()` inherit stale state. The
  reliable pattern is a **fresh `m2kOpen()` + calibrate per analog stimulus
  configuration** (~1.5 s each). Digital out is unaffected.
- Rapid close/reopen can transiently fail ("Cannot set the number of kernel
  buffers") — retry with ~1 s backoff (`open_calibrated()` helper).
- **Pattern generator start stub**: the first period after `push()` is
  anomalous; frequency/duty measurements must judge steady state only.
- **Large cyclic digital buffers get truncated** (1 Hz @ 1 MS/s ran 6%
  fast) — scale the sample rate to keep one period at ~10k samples.
- AWG sample rates snap to a discrete ladder (75 MS/s / 10ⁿ); at low rates
  the DC output droops between buffer wraps — generate DC at 750 kS/s or
  via `setVoltage()`.
- **Absolute AWG+scope accuracy stacks badly** — DMM-anchored on that unit:
  the **AWG outputs setpoint +25 mV** (constant), the **scope reads
  ~1 %/−30 mV low** (affine, drifts ~10 mV between sessions). Never assert
  DUT accuracy against M2K absolute voltages; use a **resistor divider
  from DUT VDD** (ratiometric, DMM-measured ratio) as the method of record.
  **This matters more here than it did there:** the whole FR-E03 accuracy
  budget is ±0.1 % of full travel, which the M2K cannot resolve. The M2K
  remains fine for dynamics, end stops, and anything ratio-cancelled.
- **Keep the libm2k context OPEN while the DUT-side capture runs**:
  `contextClose()` idles the AWG outputs. Measure-then-close-then-capture
  silently tests a dead stimulus (cost a full debugging afternoon).
- A "disabled" AWG channel is NOT high-impedance (~50 Ω to its idle
  level) — it cannot emulate a disconnected sensor for the FR-E07 fault
  rows; physically lift the wire instead.

## Saleae MCP quirks (inherited)

- `add_analyzer` settings need tagged values: `{"Input Channel": {"numberValue": 8}}`.
- `export_raw_data_csv` requires `analogDownsampleRatio` even for digital-only.
- Async-serial data-table CSV holds the *literal* character per byte — CR/LF
  arrive as embedded newlines inside quoted fields; don't strip.
- A capture that starts mid-byte yields garbage + one framing error before
  the first line boundary — judge from the first clean `\n` onward.
- Classic Logic16 rejects `digitalThresholdVolts` values — omit it (default
  range suits 3.3 V logic).
- **The Logic 2 Async Serial analyzer is unreliable at 9600 baud** on this
  setup — byte values scramble while the raw edges are perfect. Binary
  protocols use `saleae_serial.uart_decode()` (software UART over the raw
  edge export) instead. Also: `decode_events(..., sync_to_newline=False)`
  for binary — the text-protocol first-LF rule silently discards LF-free
  captures.

## DUT-side gotchas (inherited)

- **HDSEL idles the line floating**: in half-duplex mode the USART releases
  TX between frames; a lightly-loaded pin drifts low and every following
  frame decodes with framing errors. `common/debug_uart` therefore runs
  plain TX (idle mark driven).
- **HDSEL also intermittently swallows the first RX byte after idle**
  (~35%, no error flags) — the Modbus driver abandoned HDSEL entirely for a
  remap-switching discipline. See `software/drivers/modbus_rtu/README.md`.
- **Interrupts are suspect on this toolchain path**: an RXNE ISR corrupted
  ~1/3 of received frames with no USART error flags; polled RX fixed it
  outright. The architecture is zero-ISR — root-cause before ever adding
  one.
- **ch32v003fun SysTick default is HCLK/8**: define
  `FUNCONF_SYSTICK_USE_HCLK 1` when pacing with raw `SysTick->CNT` math, or
  everything runs 8× slow.
- **A master must release the wire immediately after its last stop bit** —
  the DUT replies ~5 ms later; holding the line driven collides with the
  reply.
- DUT-side registers exposing error counters and a last-bad-frame stash are
  worth their flash cost many times over.

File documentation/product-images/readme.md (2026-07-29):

# Product images

Supplier photographs and marketing images for the two bought-in sensors,
moved here out of `documentation/` (which holds datasheets and chip
reference material) and renamed from their original hash filenames.

**Three of these are not photographs — they carry specification data that
appears nowhere else in the repository.** Those are listed first.

## Carrying technical data

| File | What it shows |
|---|---|
| `drawwire-specification-table.avif` | **The draw-wire sensor's only specification table.** Reproduced below, because a screenshot is a poor place to keep numbers the design depends on. Also carries the working-principle schematics for the 4–20 mA, 0–10 V and **0–10 kΩ resistance** output variants |
| `drawwire-RE38-10k-2000mm-dimensions.avif` | **Identifies the exact variant to order** — "RE38 Resistance 0-10 kΩ, drawstring length 2000 mm" — with a dimensioned outline drawing (Ø38 body, mounting detail) |
| `lj18a3-connection-diagrams.jpg` | Connection diagrams for the LJ18A3 proximity-switch family. Diagram 4, *NPN NO type*: brown = +V, blue = 0 V, black = output, load between + and the output |

### The draw-wire specification, transcribed

| Parameter | Value | Bearing on this design |
|---|---|---|
| Type | Pull-cord linear position, self-resetting elastomer | — |
| Working power supply | 24 V DC | Applies to the *active* output variants only; the 0–10 kΩ variant is a passive potentiometer and needs no supply |
| Signal type | 0–10 kΩ, 4–20 mA, 0–5 V, 0–10 V | **Order the 0–10 kΩ variant.** The others break the ratiometric measurement (TDS §4.3) |
| Steel cable | 0.62 mm coated steel wire rope | — |
| Max wire speed | **100 mm/s** | The greenhouse M3 flap moves at 11.7 mm/s — 8.5× margin |
| Measuring travel | 0–1000 mm *(this image; 1.5 m and 2 m variants exist)* | M3 needs the **2000 mm** variant |
| Resolution | Infinitesimal (analogue) | The 10-bit ADC sets the resolution, not the sensor |
| Comprehensive error | **0.2 % max** | Comfortably inside the ±1 % repeatability and ±2 % accuracy the greenhouse study asks for |
| Endurance | **>100 000 cycles** | 4× the ~25 000 the greenhouse study requires over 20 years |
| Protection level | **IP50** | ⚠️ Dust only — **no water protection.** See the warning below |
| Shielding | Fitted | Helps with the actuator-noise concern |

> ⚠️ **The draw-wire unit is only IP50, and it lives outside the enclosure.**
> The IP65 box and its glands protect the electronics; they do nothing for the
> sensor itself, which hangs on the window frame in an environment that
> condenses most nights. IP50 means dust-protected and *not* water-protected.
> This is recorded as an open item in `design/TDS.md` §6 — the options are a
> sheltered mounting position, a shroud, or a higher-rated sensor.

## Photographs

| File | What it shows |
|---|---|
| `drawwire-body-1.avif` … `-5.avif` | The unit from various angles: Ø38 drum on a square alloy body, wire exit through a brass ferrule |
| `drawwire-wire-extended.avif` | Wire drawn out, showing the 0.62 mm cable and ferrule |
| `drawwire-label-0-5V-1000mm.avif` | Label of a **0–5 V, 1000 mm, 0.1 %** unit — a different variant from the one this project uses |
| `drawwire-label-5k-wiring.avif` | Label of a **5 kΩ** unit with its wiring legend — again a different variant |
| `drawwire-label-and-flying-leads.avif` | Label and flying leads together |

> Note the labels above show **0–5 V**, **5 kΩ** and **1000 mm** units. The
> supplier photographs the family, not the specific order. Do not read a
> variant off a photograph — read it off the unit that arrives.

## Not our part

| File | What it shows |
|---|---|
| `drawwire-ENCODER-VARIANT-not-our-part.avif` | Specification table for the **rotary-encoder** version of the same body: A/B/Z quadrature, open-collector / push-pull / voltage / line-driver outputs, 300 kHz, 6000 rpm, −10…+70 °C. The same mechanical unit is sold with an encoder instead of a potentiometer. **This project uses the potentiometer variant** (TDS §3.4) — that table describes a different product |

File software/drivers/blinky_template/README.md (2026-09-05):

# bare CH32V003J4M6 — PlatformIO Blinky

Minimal LED blink for a **bare WCH CH32V003J4M6** (RISC-V, SOP-8 package), built
with [PlatformIO](https://platformio.org/) using the
[ch32v003fun](https://github.com/cnlohr/ch32v003fun) framework and flashed with a
**WCH-LinkE** probe over the 1-wire SDI interface.

This is the PlatformIO counterpart to the Makefile/ch32fun `nanoCH32V003/blinky`
example. That directory lives in the project this template was carried over
from, **not** in this repo — the link here pointed at it until 2026-09-05.

## Layout

| File | Purpose |
|---|---|
| `platformio.ini` | Board, framework (`ch32v003fun`) and `wch-link` upload settings |
| `src/main.c` | Application — toggles `PD6` (100 ms on / 900 ms off; changed from the original 750/250 to make freshly flashed code visually identifiable) |
| `src/funconfig.h` | ch32v003fun compile-time configuration (defaults are fine) |

## Hardware

The J4M6 is the SOP-8 package, so there is **no on-board LED** — wire your own:

```
  PD6 ──►|── [ ~330 Ω ] ── GND
        LED
```

Usable GPIO on this package: `PA1 PA2 PC1 PC2 PC4 PD4 PD6`.
`PD1` is the **SWIO** programming line — reserve it for the WCH-LinkE.

### Wiring to the WCH-LinkE

| WCH-LinkE | CH32V003J4M6 |
|---|---|
| `3V3` | VDD |
| `GND` | VSS |
| `SWDIO / DIO` | `PD1` (SWIO) |

## Build & flash

With the [PlatformIO Core CLI](https://docs.platformio.org/en/latest/core/index.html)
(or the VS Code PlatformIO extension) installed:

```bash
pio run                 # compile
pio run --target upload # compile + flash via WCH-LinkE
pio run --target clean  # remove build artifacts
```

The `ch32v` platform, the `ch32v003fun` framework and the RISC-V toolchain are
downloaded automatically on the first build. Flashing uses the WCH OpenOCD /
`wch-link` backend that ships with the platform.

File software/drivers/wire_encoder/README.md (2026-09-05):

# Wire encoder driver — window-opening acquisition

**Status: written, HIL-verified, and integrated.** [`lib/we/we.c`](lib/we/we.c)
implements the contract in [`lib/we/we.h`](lib/we/we.h) and is linked into the
product firmware. Evidence is in `software/hil/testReport.md`; the driver's
requirements close through integration stages D and E rather than a standalone
`we_check.py`, because the acquisition is only observable through the Modbus
registers it feeds.

A draw-wire encoder is attached to the moving window frame. Its spring-loaded
drum pays out a wire and turns a **10 kΩ potentiometer**, so the wiper voltage
is a direct, absolute measure of how far the window is open. The driver reads
that wiper on **PA2** (ADC channel 0) with the 10-bit ADC in ratiometric mode
referenced to VDD:

- **16 conversions** folded per sample (FR-E13),
- **≥241-cycle** sample time (FR-E12) — see the warning below,
- a floating wiper detected by toggling the internal pull resistor between two
  conversions and comparing (FR-E07),
- and, on a separate call, the switch ladder on **PC4** (ADC channel 2).

## ⚠ The sample time is not the sibling project's

FR-E12 requires **≥241 cycles here**, where the sibling wind vane uses ≥71. The
difference is FR-E21's **10 kΩ series protection resistor**, which the vane does
not have: it lifts the DC source impedance from the element's 2.5 kΩ at
mid-scale to **12.5 kΩ**, above the 10 kΩ the ≥71 figure was chosen for.

This is called out because the driver **shipped wrong once** for exactly this
reason. It was written to `we.h`'s front-end note, which still carried the old
"≥71 cycles", and configured 73. The header was a copy of the requirement and
had already drifted. **Read FR-E12 in `design/TDS.md`, not a comment that
paraphrases it** — including this one. Full write-up in `docs/gotcha-log.md`.

## The contract

```c
void     we_init(void);                   /* front-end bring-up per FR-S18 step 3    */
bool     we_sample(uint16_t *raw);        /* wiper: one acquisition; false = invalid */
bool     we_switch_sample(uint16_t *raw); /* end-switch ladder, ADC channel 2        */
uint16_t we_raw_max(void);                /* 1023 — 10-bit ADC full scale            */
```

The scope is deliberately narrow: **produce a raw code and say whether it is
trustworthy.** Scaling (FR-E04), offset, windowing, averaging, the 2-second
FR-E07 fault hold and the FR-E23/FR-E24 health checks all live above the driver.
`we_sample()` returning false means *this sample is unusable*, not *the sensor
has failed* — that distinction is what keeps the driver testable in isolation.

Note that FR-E07 detects **opens only**. A wiper shorted to either rail is
indistinguishable from a legitimate end-stop reading, because FR-E21's series
resistor makes the two electrically identical. That is a deliberate, documented
limit, not a gap in the implementation.

## Cost, and why it matters

A conversion is ~21 µs at 241 cycles with the ADC clocked at 12 MHz
(`RCC_ADCPRE_DIV4`), so `we_sample()` costs ~0.34 ms against a ≥100 ms
measurement window. Cheap in that budget — but **not** against the one budget no
requirement states:

> `mb_rx_service` polls a single-byte USART register. Any main-loop pass longer
> than **one character time (1.146 ms at 9600 baud)** loses a byte to overrun,
> and FR-MB24 discards the frame — *without* incrementing 30009, because an
> overrun is not a CRC error. Requests simply vanish.

That is why `meas_open.c` services the wiper and the switch ladder on
**alternate ticks**: no single pass pays for both. Integration stage D dropped
9.7 % of requests before this was understood. If you add work to this path,
measure the pass time, not just the window budget.

## Bench notes that will save you a day

Learned here and in the sibling project, each at real cost:

- **Do not judge a ratiometric ADC against M2K absolute voltages.** The AWG
  outputs setpoint +25 mV and the scope reads ~1 %/−30 mV low. Use a resistor
  divider from the DUT's own 3.3 V rail with a DMM-measured ratio; the
  ratiometric conversion cancels everything else. FR-E03's budget is ±0.1 % of
  full travel, which the M2K cannot resolve. **FR-E03 remains open** for want of
  a precision resistance box at five ratios.
- **A "disabled" M2K AWG channel is not high-impedance** (~50 Ω to its idle
  level) — it cannot emulate a disconnected wiper for the FR-E07 fault rows.
  Physically lift the wire.
- **Keep the libm2k context open** while the DUT-side capture runs;
  `contextClose()` idles the outputs and you will silently test a dead stimulus.
- **The real mechanism is the other half of the accuracy budget.** A divider
  proves the electronics; only the actual draw-wire on the actual window proves
  the installation. FR-E03 covers the first; the second is a separate item.
- **An electrically perfect wiper can still be lying.** A draw-wire that is
  snapped, tangled or slipping reads as a stable, plausible constant and passes
  every check in this driver. That fault is caught above the driver, by FR-E23.

## Reference implementation

The sibling
[`windmeters-modbus-interface`](https://github.com/pe1mew/windmeters-modbus-interface)
project's `wind_direction` driver reads an 11 kΩ potentiometer on the same pin
with the same float-detection trick. It was the starting point — but copy its
*structure*, not its register values, and check every setting against this
project's requirements before reusing it. The one setting that differs is the
one that caused the bug above.

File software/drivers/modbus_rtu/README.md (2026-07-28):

# Modbus RTU slave driver — USART1 on PD6, DE/RE on PC2

Implements the TDS §2 driver layer: framing/CRC, t3.5 gap detection,
address filtering, FC03/04/06/16, standard exceptions, no-clamp range
rejection, atomic FC16, quantity validation, big-endian data /
little-endian CRC, FC06 echo & FC16 confirm responses, and app-owned
register semantics (holding table with min/max, input-read callback,
cross-validate hook for FR-S31 and FR-E06).

> **Provenance.** This driver is carried over unchanged from the sibling
> [`windmeters-modbus-interface`](https://github.com/pe1mew/windmeters-modbus-interface)
> project, phase 3. The verification below was performed **there**, on the
> same MCU and the same framework, but not on this project's hardware —
> there is no hardware here yet. Fix bugs in both places.

## HIL verification (source project, 2026-07-03, TTL rig, no transceiver)

`mb_check.py`, M2K as bit-banged open-drain master on the shared PD6 wire,
Saleae raw-edge decode:

- **26/26 matrix vectors** covering FR-MB02/05/06/08–15/19/22/25/28/30 and
  the cross-register constraint via the hook
- **40/40 endurance transactions**, zero loss
- **Response latency: median 5.2 ms, worst 5.2 ms** (FR-MB21 typical <15 ms,
  FR-MB20 hard <100 ms)

Later, through a MAX3485: 1000/1000 requests at 4.07/4.12/4.17/4.44 ms
(min/med/p99/max), plus split-frame, garbage-flood and off-baud vectors.

## Two hard-won design decisions (bench-forced, both product-relevant)

**1. No HDSEL — remap-switching line discipline.** In HDSEL single-wire
mode this part intermittently (~35%) swallowed the FIRST byte after bus
idle with no error flags (wire verified pristine at 10 MS/s; the stashed
frame was the request minus its address byte). Instead the driver uses the
SOP-8 remap geometry: the DEFAULT USART map has **RX natively on PD6**;
`mb_send()` temporarily switches to partial remap 2 (TX→PD6), transmits,
and switches back. Modbus is strictly request/response, so the direction is
always known. Side benefit: no self-echo during reception (FR-MB23
satisfied by flag-clearing around the TX window).

**2. Polled RX — zero interrupts.** With the RXNE ISR, ~1/3 of frames
reached the parser with missing/scrambled leading bytes while the USART
never flagged an error — symptoms of ISR prologue/state corruption on this
toolchain path (`__attribute__((interrupt))` on RV32EC, unconfirmed root
cause; treat ANY interrupt use in this project as suspect until
investigated). Polling from the main loop (~1 µs cycle vs 1042 µs per
byte) is provably lossless and removed every failure instantly:
26/26 + 40/40 vs the ISR build's chaos.

**Neither is a candidate for cleanup.** Both look like workarounds and both
cost real bench days to find.

## Diagnostics (exposed as shell input registers)

`mb_crc_error_count` / `mb_served_count` (published as 30009/30010 by this
project's register image), plus bench registers: FE/NE/ORE counters and a
last-CRC-fail frame stash (len, first bytes, received CRC) — the stash is
what cracked the first-byte-loss hunt.

## API (`lib/mb/`)

```c
mb_config_t cfg = {.address, .holdings, .n_holdings,
                   .input_read, .cross_validate};
void mb_init(const mb_config_t *cfg);
void mb_poll(void);   // main loop; self-timed via SysTick->CNT
```

The test shell in `src/main.c` is the source project's phase-3 harness; it
exercises the driver against a small stand-in register table. Retarget it
to this project's map (TDS §2.7/§2.8) before running `mb_check.py` on a
board here.

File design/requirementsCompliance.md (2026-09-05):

# Compliance check — greenhouse-Controller M3 window position sensor

| Field | Value |
|---|---|
| Document | Requirement compliance analysis |
| Project | `wire-encoder-modbus-interface` |
| Date | 2026-07-28 |
| Checked against | `greenhouse-Controller/design/windowPositionSensorRequirements.MD`, dated 2026-07-28 (marked PRELIMINARY STUDY — not adopted) |
| This design | `design/TDS.md` **v0.7**, `design/description.md` |
| Status | Updated through TDS v0.7. The two gaps this analysis originally raised are both closed; what remains is listed in §4. **Annotated 2026-09-05 with the target window's actual figures — 1.5 m stroke, 171 s to open or close, the M3 travel time (8.77 mm/s, 0.585 %/s).** The study assumed a 2 m stroke; every figure derived from it is re-derived below in a *"1.5 m:"* note, with the study's original left in place. The study's 0.58 %/s in FR-WP20 turns out to be this window's *nominal* speed, so it cannot be used as a rejection limit without margin. |

---

## 1. Verdict

**The functional and protocol design is a strong match — in several places an
exact one. The environmental gaps identified in the first pass of this
analysis have since been closed** (TDS v0.4: §4.5 enclosure strategy,
NFR-ENV02…05). What remains is one procurement condition, not a design gap.

*Updated 2026-07-28 after TDS v0.4, which also closed the direction-of-travel
limitation this analysis had flagged as a live risk.*

The requirements study independently arrives at "draw-wire, Modbus RTU,
absolute" as its preferred technology (§9) — which is what this device is.
Of the three requirements it names as most likely to make a purchase useless,
this design satisfies all three by construction.

| Area | Requirements | Verdict |
|---|---|---|
| What it measures (§2) | FR-WP01…07, 21, 22 | **Met**, subject to the sensor unit's own accuracy |
| Timing (§3) | FR-WP08, 09, 10 | **Met**, with a maximum-age contract (FR-E17). The shipped default window is too long for this application and must be set at commissioning |
| Modbus/electrical (§4) | FR-WP11…15, NF-WP01, 02 | **Met**, except FR-WP11 partially and a connector mismatch |
| Environment (§5) | NF-WP03…08 | **Addressed** by the §4.5 enclosure strategy and NFR-ENV02…05. NF-WP03's +70 °C is now met (2026-08-29 sensor change); the draw-wire unit's IP50 rating remains the open point |
| Failure behaviour (§6) | FR-WP16…20 | **Met** for the parts that are the sensor's to meet |

Counting only what is this device's responsibility: **28 met, 2 met with
caveats, 4 belong to the controller** — NF-WP03 moved into the met column on
2026-08-29 with the end-switch change. The procurement conditions this
analysis originally raised — wiper life and mechanism accuracy — are both
closed by the supplier specification. The three that remain are in §4, and
only one of them is a requirement missed outright rather than narrowed with
its cause named: **NF-WP05, because the draw-wire unit is IP50 and lives
outside the box.** It is now the *only* such requirement — the temperature
ceiling that used to keep it company is closed.

---

## 2. Compliance matrix

### 2.1 What the sensor must measure

| ID | Req (abbreviated) | Verdict | Evidence / note |
|---|---|---|---|
| FR-WP01 | Monotonic position over full stroke | ✅ **Met** | 30001, 0.1 mm units, 0–65534. The 2 m stroke is 20 000 units — well inside range. *1.5 m: 15 000 units* |
| FR-WP02 | Absolute; valid at power-on, no homing | ✅ **Met — core design property** | FR-E01. A potentiometer carries position in the sensor; there is nothing to home and nothing to lose. Directly removes their §1.3 |
| FR-WP03 | Measured at the leaf, not the motor shaft | ✅ **Met by construction** | The wire attaches to the moving flap. Immune to drum-radius nonlinearity, rope stretch and slip — the exact failure modes their §1.4 item 2 raises |
| FR-WP04 | Resolution ≤ 1 % of stroke | ✅ **Met, ~10× margin** | 1023 ADC counts over a 2 m stroke = **1.96 mm/count = 0.098 %**. Even if the potentiometer spans only half the ADC range, 0.2 % still clears it 5×. *1.5 m: 1.47 mm/count — the percentage is the same 0.098 %, since it is 1/1023 of whatever the stroke is; with the §8.1 headroom (~80 % of range used) ≈1.8 mm/count, 0.12 %* |
| FR-WP05 | Repeatability ≤ ±1 % over temperature | ✅ **Met** | FR-E03 firmware budget is ±0.1 % of full travel, stability ≤3 LSB (≈5.9 mm ≈ 0.29 %). Ratiometric operation cancels supply drift. The draw-wire unit's own **comprehensive error is 0.2 % max** (supplier specification, transcribed in `documentation/product-images/readme.md`), so the mechanism's share is well inside the budget |
| FR-WP06 | Absolute accuracy ≤ ±2 % (Should) | ✅ **Met** | Firmware ±0.1 %, mechanism 0.2 % — an order of magnitude inside the ±2 % asked |
| FR-WP07 | Fully-closed distinguishable from near-closed (Should) | ⚠️ **Met only if the end sensors are positioned correctly** | Status bit 3 says a stop was reached; the reported position says which. **But bit 3 reports the SENSOR, not the window.** If a sensor's active zone is narrow and the leaf can travel past it — the normal geometry on a real window, see `description.md` §8.1 — then bit 3 reads *not at a stop* with the window fully closed, and this requirement is **not met in that installation**. Verified 2026-09-01 on the test rig, whose sensors stay active from actuation through to the mechanical limit, so bit 3 held for 30 s while parked with zero dropouts (EM-M05). That is a property of how the rig is built, not of the firmware. **Correction 2026-09-01:** this row previously said an open sensor cable *"now reads as a stop"* — that was the NPN-era behaviour and has been wrong since the PNP change of 2026-08-29. Under the present part an open cable reads ~0 counts, i.e. **neither active**, so it reports a *missed* stop, not a false one (TDS §4.4.6) |
| FR-WP21 | Tolerate wind sway; report *mean* not instantaneous; filtering within FR-WP09 | ✅ **Met, with a bonus** | 30002 is a configurable boxcar mean; set to 1 s it satisfies both this and FR-WP09 (§3 below). **Bonus:** 30003/30004 report the min/max envelope over the averaging period — i.e. they *quantify the billowing amplitude*, which the study asks about but does not request a means to measure |
| FR-WP22 | Measurement point representative of a 40 m span | ➖ **Installation matter** | Firmware is agnostic. Note two devices can share the segment (addresses 40 and 45), so characterising both ends is possible without new hardware |

### 2.2 Timing — the section that needs action

| ID | Req | Verdict | Evidence / note |
|---|---|---|---|
| FR-WP08 | ≥1 Hz, **fresh** value each read | ✅ **Met — now an explicit contract** | **FR-E17**: the value in 30001 is never older than the configured measurement window. "Fresh" is therefore a number the master sets, not a hope. It **defaults to 1000 ms**, so 40002 must be set to 100–200 ms at commissioning for this application — see §3. With 200 ms the worst-case staleness is 2.3 mm, 0.12 % of the 2 m stroke. *1.5 m at 8.77 mm/s: 200 ms → 1.8 mm (0.12 %); **500 ms → 4.4 mm (0.29 %)**; 1000 ms → 8.8 mm (0.58 %). The literal "fresh at every 1 Hz read" needs 40002 shorter than the poll period, so 500 ms for a 1 Hz poll; going below that moves the leaf less than one ADC count per update and gains nothing — see §3* |
| FR-WP09 | Filtering ≤ ~1 s group delay, or configurable to it | ✅ **Met** | Two routes. (a) Read 30001 — instantaneous, no filtering beyond the measurement window. (b) Read 30002 with 40003 = 1 s: a 1 s boxcar, group delay ≈ 0.45 s. The FR-E13 16-conversion burst takes <1 ms and adds no meaningful delay |
| FR-WP10 | Transaction ≤200 ms; ≤50 ms preferred | ✅ **Met with wide margin** | FR-MB20 hard limit 100 ms; FR-MB21 95 % within 15 ms. **Measured on this device (TP-B14/TP-B29, 2026-09-01): 4.08 ms median, 4.14 ms worst over 1000 requests, 100 % within 15 ms.** Timed from the DE edge on the wire, not from host round-trip. Essentially all of it is the mandatory t3.5 frame-boundary silence (4.01 ms); the firmware adds ~20 µs. The sibling project's 4.12 ms median on the same driver binary corroborates it |

**AT-WP04 check.** At 11.7 mm/s the flap moves 11.7 mm per second ≈ **6 ADC
counts per second**. Polling at 1 Hz therefore yields distinct, monotonic
values throughout a 171 s stroke with comfortable margin — provided 40002 is
short enough that each poll lands on a fresh window.

*1.5 m, 171 s: 8.77 mm/s ≈ **5–6 counts per second** (6.0 over the full ADC
range, ≈4.8 with §8.1 headroom), over the same 171 s stroke — the study's
speed figure was right; only its stroke was not. The conclusion holds. The
corollary cuts the other way for the measurement window: at 100 ms the leaf
moves ≈0.5 count per update, so consecutive updates are identical about half
the time and the rate register 30012 quantises to steps of ≈180 — twice the
88 it is trying to report. 500 ms (≈2.4 counts/update, 30012 steps ≈37) is the
shortest window that resolves both position and rate on this actuator.*

### 2.3 Modbus and electrical

| ID | Req | Verdict | Evidence / note |
|---|---|---|---|
| FR-WP11 | Address user-configurable without returning the unit | ⚠️ **Partially met** | Address is a **solder jumper**: 40 (open) or 45 (bridged). Settable by the user, and both are clear of the addresses in use (1, 44). But it is two fixed values, not an arbitrary address, and setting it means opening the enclosure with a soldering iron. There is deliberately **no address register** (FR-MB07) — a design decision, not an oversight. Adequate for one M3 sensor; a constraint if the fleet grows |
| FR-WP12 | Position in a **single transaction**, atomic w.r.t. motion | ✅ **Met — explicitly designed for** | FR-S24 requires every value in one response to be a coherent snapshot from one measurement update, never a mixture of two windows. The registers are contiguous (30001–30012) |
| FR-WP13 | No broadcast, no master behaviour, no proprietary framing | ✅ **Met** | Pure slave (FR-S19, never transmits unprompted). Standard FC03/04/06/16 only. Broadcast is deliberately ignored (FR-MB06) |
| FR-WP14 | Observe 3.5-char silence, release the line promptly | ✅ **Met, HIL-verified** | FR-MB03 (t3.5 framing), FR-MB04 (DE de-asserted within one character time). Verified on the bench in the sibling project |
| FR-WP15 | Manufacturer-documented register semantics | ✅ **Met** | TDS §2.7/§2.8 give address, function code, unit, range, default and requirement ID per register. Endianness is normative (FR-MB25: big-endian data, little-endian CRC). `design/description.md` is the integrator-facing version |
| NF-WP01 | Supply should match what is distributed (+24 V) | ✅ **Met** | The power chain accepts **24 V**. The field cable enters through a gland and terminates inside the enclosure (§4.5), so the incoming conductors are +24 V/GND/A/B on the installation's own terms rather than requiring a particular plug |
| NF-WP02 | Reuse the junction arrangement; daisy-chain, no stubs, termination practice | ✅ **Met** | Two connectors for daisy-chaining, 120 Ω terminator behind a jumper, A/B fail-safe bias, TVS — all inside the sealed enclosure, cables glanded |

### 2.4 Environment — closed in TDS v0.4, ingress figure settled in v0.5

The first pass of this analysis found nothing specified here. TDS §4.5 and
NFR-ENV02…05 now cover it: an IP65 enclosure with every connector inside it,
field cables through glands, terminal blocks for the sensor and switch loop,
mounted out of direct UV, and the board itself protected against condensation
rather than relying on the seal alone.

| ID | Req | Verdict | Note |
|---|---|---|---|
| NF-WP03 | −20 °C to +70 °C | ✅ **Met — closed 2026-08-29** | NFR-ENV01 is **−25 °C to +70 °C**. It was narrowed to +65 °C on 2026-07-29 because the LJ18A3-8-Z/BX end switch capped it there, and this row then carried the note that it was *the one requirement the design knowingly does not meet in full*. Replacing that sensor with the **3RG4023-3AB00**, rated **−25…+85 °C**, removes the constraint: the sensor is no longer the narrowest part and the limit reverts to the electronics, which carry +70 °C. The predicted fix — "a wider-range end switch" — is exactly what happened, arriving as a change of part rather than as a survey. *Evidence gap:* +70 °C is inherited from the sibling project's part set and still needs the NFR-ENV01 chamber run to become measured rather than asserted |
| NF-WP04 | 100 % RH, condensing | ✅ **Met** | **NFR-ENV02.** Sealed and glanded enclosure, plus protection of the board itself against condensation (conformal coating the recommended default) — because a sealed box in a swinging temperature still breathes. The acceptance criterion is a condensing-night cycle, which is AT-WP08 |
| NF-WP05 | IP65 minimum, IP67 preferred | ⚠️ **Enclosure meets the minimum; the sensor does not** | **NFR-ENV03: IP65.** The earlier RJ45 objection dissolves once the connectors are *inside* the box: ingress protection is a property of the enclosure and its glands, so an ordinary connector in a sealed enclosure is fine (§4.5). The selected **Kopp 99966478 is IP65** — the stated minimum, and NFR-ENV03 was narrowed to match it rather than claim an IP67 the BOM does not deliver. The study's IP67 preference was for hardware *at the aperture*; this box is not. **But the draw-wire unit itself is only IP50** and necessarily sits outside it on the window frame. That is the weakest environmental point in the design — see §4 |
| NF-WP06 | UV and greenhouse chemical resistance | ✅ **Met** | **NFR-ENV04.** Mounted out of direct UV inside the greenhouse structure, which is the shaded-position answer; where an installation cannot guarantee that, the requirement falls back to a UV-stabilised enclosure |
| NF-WP07 | Tolerate motor vibration and end-stop shock without drift | ✅ **Met** | **NFR-ENV05**, with a 100-cycle acceptance criterion covering both the persisted calibration and mechanical mounting drift |
| NF-WP08 | ~25 000 cycles / 20 years; **contacting technologies must be assessed** | ✅ **Met on both counts.** The end switches are inductive proximity sensors — non-contact, so the concern does not apply. The draw-wire unit is specified at **>100 000 cycles**, 4× the ~25 000 needed over twenty years | The sensor is a potentiometer — precisely the contacting wiper technology this requirement singles out. A conductive-plastic element will manage 25 000 strokes comfortably; a cermet or wirewound one may not. **This must be specified when the draw-wire unit is bought.** Partial mitigation: the two-point calibration is re-teachable, so wear that shifts the endpoints can be corrected in the field rather than requiring replacement |

### 2.5 Failure behaviour

| ID | Req | Verdict | Evidence / note |
|---|---|---|---|
| FR-WP16 | Failure detectable; no stale, frozen or plausible-but-wrong data | ✅ **Met — with one honest limit** | A disconnected or shorted wiper reports **65535** in all four position registers plus status bit 2 (FR-E07) — an explicit, out-of-band error, not silence and not a plausible number. 30011 (seconds since last valid reading) catches the "readings stopped without the detector tripping" case. **Two limits.** No position sensor can detect a *slipped wire* — it produces a plausible wrong reading; the end switches are the partial defence, and FR-WP03/AT-WP09 puts the rest in the controller as commanded-vs-measured divergence. And the end switches have a plausible-but-wrong mode of their own: an open sensor cable is undetected. Note the *direction* changed on 2026-08-29 — under the previous NPN sensor a cut read as a **false** stop; under the PNP 3RG4023-3AB00 it reads as a **missed** stop. Neither is flagged, and the fault band is gone entirely, because a PNP normally-open output looks the same inactive, open-circuit and shorted to 0 V. The wiper path still meets this requirement in full; the switch path now has a documented gap, and the same controller-side divergence check is its best defence too |
| FR-WP17 | Controller falls back to time-based control | ➖ **Controller-side** | This device's contribution is making the failure unambiguous so the fallback can trigger |
| FR-WP18 | Wind override must not depend on position | ➖ **Controller-side** | Nothing here creates such a dependency |
| FR-WP19 | Fault surfaced to the operator | ➖ **Controller-side** | Status bits 2 and 4 are the raw material |
| FR-WP20 | Reject implausible readings / jumps >0.58 %/s (Should) | ✅ **Directly supported** | 30012 reports the movement rate the device measured. 0.58 %/s of a 2 m stroke = 11.7 mm/s = **117** in the register's 0.1 mm/s units — a ready-made plausibility threshold. ***1.5 m, 171 s — the study's 0.58 %/s is this window's nominal speed, not a limit.** 1500 mm / 171 s = 8.77 mm/s = **0.585 %/s**, so the figure was clearly derived from the real travel time. Used directly as the rejection threshold it has zero margin: 30012 reads ±88 in a healthy traverse, plus ±37 of quantisation at 40002 = 500 — a legitimate reading of 125 would be rejected. On the 1.5 m stroke the study's own number is 87 in 30012 units (not the 117 computed above for 2 m). The controller's limit must sit above nominal with margin: **\|30012\| > 175** (17.5 mm/s, twice nominal) — `docs/modbusInterfaceContractSpecification.md` §4.6/§8.1. The requirement's intent — reject jumps the actuator cannot produce — is met; its number is the actuator's speed and needs a factor on top* |

---

## 3. Configuration required at commissioning

The shipped defaults are tuned for a slow monitoring application and **do not
meet FR-WP08**. For closed-loop M3 positioning:

| Register | Default | Set to | Why |
|---|---|---|---|
| 40002 measurement window | 1000 ms | **100–200 ms** — *1.5 m: **500 ms** for a 1 Hz poll, 1000 if the controller polls at ≤0.5 Hz* | FR-WP08: a fresh value at every 1 Hz poll. At 1000 ms a poll can return a value up to a second old, and consecutive polls may repeat. *1.5 m, 8.77 mm/s: below 500 ms the leaf moves under one ADC count per update and 30012 quantises into steps larger than the speed itself (AT-WP04 note above); 100–200 ms buys traffic, not information* |
| 40003 averaging window | 10 s | **1 s** | FR-WP09: caps group delay at ≈0.45 s. Only matters if the controller reads 30002; reading 30001 sidesteps filtering entirely |
| 40004 full travel | 10000 (1000.0 mm) | **20000** (2000.0 mm) — *1.5 m: **15000**, then replace with the tape-measured sensor-to-sensor distance* | The measured M3 stroke. *The study's 2 m was an assumption; the window being fitted is 1.5 m. The value written must be the distance between the two end-sensor operating points, not the hard stops — a teach captures those points, and 40004 must match them* |
| 40005 / 40006 raw calibration | 0 / 1023 | measured | The commissioning procedure in `description.md` §6 |

Both settings satisfy the FR-S31 cross-check (40003 × 1000 ≥ 40002) and
persist across power loss.

**Which register should the control loop read?** **30001** (instantaneous).
It is unfiltered beyond the measurement window, which is what a positioning
loop wants. 30002/30003/30004 are for the wind-sway question (FR-WP21) and
for diagnostics, not for stopping the motor.

> Worth considering: if this device is only ever used for closed-loop
> positioning, the 40002 default should change from 1000 ms to 200 ms so it
> is right out of the box. That is a one-line change to TDS §2.8 and is
> cheaper to make now than to remember at every commissioning.

---

## 4. Gaps that need a design decision

**Both gaps this analysis originally raised are now closed**, by the
draw-wire supplier specification found in the product images
(`documentation/product-images/readme.md`):

| Originally raised | Closed by |
|---|---|
| Potentiometer life (NF-WP08) — "specify a conductive-plastic element" | **>100 000 cycles** specified, 4× the ~25 000 needed over twenty years |
| Sensor accuracy (FR-WP05/06) — "the mechanism's share must be specified" | **0.2 % comprehensive error**, an order of magnitude inside the ±2 % asked |

Three gaps have replaced them. Two arrived with the parts that were chosen
afterwards, which is the ordinary way of things — a compliance analysis
against a *design* becomes an analysis against a *bill of materials* as soon
as parts are picked, and the narrowest part sets the answer.

1. **The draw-wire unit is IP50 and sits outside the enclosure (NF-WP05).**
   This is the weakest environmental point in the design and the only one
   where a requirement is missed outright rather than narrowed. NF-WP05 asks
   ≥IP65 of the sensor; IP50 is dust-protected and not water-protected, in a
   greenhouse that condenses most nights. The IP65 box protects the
   electronics and does nothing for the sensor. Options: a sheltered mounting
   position, a shroud, or a higher-rated unit.

2. ~~**Ambient ceiling +65 °C against +70 °C asked (NF-WP03).**~~ **CLOSED
   2026-08-29** by replacing the LJ18A3-8-Z/BX with the 3RG4023-3AB00, rated
   −25…+85 °C. The old entry said the fix was "a wider-range switch"; that is
   what happened. What replaces it is smaller and different in kind: the
   +70 °C figure is now an assertion about the **electronics**, inherited from
   the sibling project rather than measured here, and it needs the NFR-ENV01
   chamber run to become evidence.

3. **Address configurability (FR-WP11).** A solder jumper giving two fixed
   addresses, not an arbitrary one. Adequate for a single M3 sensor and clear
   of the addresses in use; a constraint only if the fleet grows. Unchanged
   since the first pass and deliberate (FR-MB07).

Note what is *not* on this list any more: the enclosure. NFR-ENV03 was
narrowed from IP67 to IP65 to match the selected Kopp 99966478, which meets
NF-WP05's stated minimum for hardware not mounted at the aperture.

---

## 5. Where this design gives more than was asked

Worth knowing, because some of it addresses problems the study raises but
does not request a solution for:

- **Supervised switch cable.** FR-WP07 asks only for a closed indication.
  This design distinguishes cable-open, healthy, at-a-stop, both-closed and
  cable-shorted — so a cut switch cable cannot masquerade as "not at a stop".
  Given FR-WP16's insistence on never returning plausible-but-wrong data,
  that is aligned with the intent rather than merely the letter.
- **Movement envelope (30003/30004).** Min and max over the averaging
  period. For a hanging flap that billows (FR-WP21), this measures the sway
  amplitude directly rather than merely tolerating it.
- **Movement rate (30012).** A ready-made input to FR-WP20's plausibility
  check, and a direct answer to "is the actuator actually running?" — which
  bears on their §1.2 open-loop blindness.
- **Bus health counters (30009/30010).** CRC-error and served-request counts
  support AT-WP05's 24-hour coexistence test with evidence from the device's
  own side, not just the master's.
- **Field-recalibratable endpoints.** Partially offsets the NF-WP08 wear
  concern: a worn wiper whose endpoints have shifted can be re-taught over
  Modbus rather than replaced.

---

## 6. What this study changed here

Acted on in TDS v0.4:

- **Direction of travel — fixed.** The study made this concrete: M3 is
  *raised to close, lowered to open*, so whether the wiper code rises or falls
  depends entirely on how the draw-wire is mounted — a 50/50 risk on a real
  installation rather than a theoretical one. FR-E04 now accepts the
  calibration points in either order, host-tested in both senses.
- **Environment — specified.** §4.5 and NFR-ENV02…05.

Still open, and informed by the study:

- **Auto-calibration stopped being a convenience and became a diagnostic.**
  The study's §1.2 asks for mechanical fault detection — slip, obstruction, a
  window blocked part-way — and AT-WP09 tests exactly that. A slipped wire is
  the one failure this sensor cannot otherwise see, because it yields a
  plausible wrong reading; the end switches are its only independent physical
  reference. Comparing the raw code at a stop against the stored endpoint
  measures the drift directly, without relying on the controller's
  travel-time model the way their commanded-versus-measured scheme does.
  Analysis in `design/scratchBook.md` §Q1, tracked in TDS §6.
- **The movement rate became signed** (FR-E10, 2026-07-29), which serves
  FR-WP20 better than a magnitude: the controller sees a jump's direction as
  well as its size, and for a hanging flap "moving down" and "moving up" have
  different mechanical meanings (their §1.4 item 3 — the drive is asymmetric
  and directional hysteresis is expected). A **percentage-of-travel register**
  (30015, FR-E20) was added at the same time, so a master no longer divides by
  40004 to get the number it actually wants.

---

*Analysis only. The source document is itself marked PRELIMINARY STUDY —
not adopted — so nothing here should be treated as an agreed requirement on
this project.*

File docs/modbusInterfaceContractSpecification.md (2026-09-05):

# Modbus Interface Contract — Window Opening Sensor ↔ Greenhouse Controller

| | |
|---|---|
| Document | Client-facing interface contract for the wire-encoder window-opening sensor |
| Version | 1.2 (2026-09-05 — §8 re-derived for the target window: 1.5 m in **171 s**, the M3 travel time; FR-WP20 threshold given margin) |
| Audience | The **greenhouse controller** (Modbus master) — its firmware author and its integrator |
| Derived from | `design/TDS.md` **v0.7**, which is normative. Every statement here cites the requirement it comes from; where the two disagree, the TDS wins and this document is wrong |
| Firmware | Build type `0x01`, version 1 — read it from register 30007 before trusting anything below |
| Verification | Every behaviour described here is HIL-verified unless marked **not yet verified**; evidence in `software/hil/testReport.md` |

---

## 1. What this document is for

The sensor is a pure Modbus RTU slave that reports **how far a window is open**,
whether it is **at an end stop**, and **whether its own readings can be
trusted**. This document tells the controller four things:

1. **Where** each piece of information lives (register, function code, unit,
   encoding).
2. **What it means** — including what it does *not* mean, which matters more.
3. **How to teach** the sensor its end points over the bus.
4. **Which indications are alarms**, which are health, and what the
   controller should do about each.

It is organised by *purpose* (§4–§7), with the flat register map in §3 for
reference. Read §2 first: two of the sensor's behaviours are deliberate
deviations from the Modbus standard, and one register is signed.

---

## 2. The link — facts the controller must build in

| Property | Value | Source |
|---|---|---|
| Physical / framing | RS-485, Modbus RTU, **9600 baud, 8N1** | FR-MB01 |
| Slave address | **40** (solder jumper open) or **45** (bridged). Fixed at power-on. **There is no address register** — the address cannot be read, set or discovered over the bus | FR-S03, FR-MB07 |
| Function codes | **FC04** read input, **FC03** read holding, **FC06** write single, **FC16** write multiple. Anything else → exception 01 | FR-MB08–12 |
| Byte order | Register data **big-endian** (high byte first). CRC-16 **low byte first** | FR-MB25 |
| Signedness | **Every register is unsigned except 30012**, which is two's-complement `int16` | §2.7 |
| Response time | ≤100 ms hard; 95 % within 15 ms. **Measured: 4.08 ms median, 4.14 ms worst over 1 000 requests** | FR-MB20/21 |
| Inter-frame gap | 3.5 character times ≈ **4.0 ms** at 9600. Leave ≥5 ms between requests | FR-MB03 |
| Max read | 15 input registers (`0x0000–0x000E`), 7 holding (`0x0000–0x0006`). A read that touches any address beyond the map → exception 02 **for the whole request**, no partial data | FR-MB13/14/27 |
| Exceptions | Only **01, 02, 03**. Code 04 is **never** emitted | FR-MB18/29 |
| Silence | A valid, addressed request **always** gets a reply — normal or exception. Silence means bad CRC, wrong address, broadcast, or a physical problem | FR-MB02/05/17 |

### 2.1 Deliberate deviations from the Modbus standard

- **Broadcast (address 0) is ignored** — not executed, not answered. The
  standard requires slaves to execute broadcast writes; this device does not,
  so that a fleet can never be reconfigured by one stray frame (FR-MB06).
- **No address register.** Two devices per bus segment, 40 and 45, period.
  More instrumented windows need a hardware change (FR-MB07, FR-WP11).

### 2.2 Write semantics the controller can rely on

- A write that returns success **took effect**. A write that returns exception
  03 **changed nothing** — the device never clamps a value into range and never
  echoes success while discarding (FR-MB19).
- **FC16 is atomic.** If any register in the request is invalid — including the
  two cross-register rules in §8 — the whole request is rejected and *no*
  register changes, not even the valid ones (FR-MB22).
- FC06's success response is a byte-exact echo of the request (FR-MB30).
- Settings **persist** across power loss (FR-S39). The controller need not
  re-send configuration after a sensor restart — with one exception, §5.5.

---

## 3. Register map — reference

Modicon numbering (3xxxx / 4xxxx) is what the tables use; the raw PDU address
is one less than the last digits. `30001` = raw `0x0000`.

### 3.1 Input registers — FC04, read-only

| Raw | Reg | Meaning | Unit | Range / encoding | Purpose (§) |
|---|---|---|---|---|---|
| `0x0000` | 30001 | Opening, **instantaneous** | 0.1 mm | 0–65534; **65535 = sensor fault** | §4 |
| `0x0001` | 30002 | Opening, **averaged** | 0.1 mm | as above | §4 |
| `0x0002` | 30003 | Opening, **minimum** in current averaging window | 0.1 mm | as above | §4 |
| `0x0003` | 30004 | Opening, **maximum** in current averaging window | 0.1 mm | as above | §4 |
| `0x0004` | 30005 | Raw ADC code, pre-calibration | counts | 0–1023 | §6, §8 |
| `0x0005` | 30006 | **Status bits** | bitfield | see §3.3 | §5, §7 |
| `0x0006` | 30007 | Identification | — | high byte build type (`0x01` release, `0x81` bench build — **do not deploy**), low byte firmware version | §9 |
| `0x0007` | 30008 | Uptime since reset | s | 0–65535 saturating | §7 |
| `0x0008` | 30009 | Bus CRC error count | — | wraps | §7 |
| `0x0009` | 30010 | Served request count | — | wraps | §7 |
| `0x000A` | 30011 | Seconds since last **valid** sensor reading | s | 0–65535 clamped | §7 |
| `0x000B` | 30012 | **Movement rate — SIGNED** | 0.1 mm/s | `int16`; + opening, − closing, 0 at rest | §4, §7 |
| `0x000C` | 30013 | Raw code captured at last **closed-end** stop | counts | 0 = none since reset | §6 |
| `0x000D` | 30014 | Raw code captured at last **open-end** stop | counts | 0 = none since reset | §6 |
| `0x000E` | 30015 | Opening as **percentage** of full travel | 0.1 % | 0–1000; 65535 = fault | §4 |

### 3.2 Holding registers — FC03 read, FC06/FC16 write

| Raw | Reg | Meaning | Unit | Valid | Default | Persists |
|---|---|---|---|---|---|---|
| `0x0000` | 40001 | Zero offset reported at the closed point | 0.1 mm | 0–65534 | 0 | yes |
| `0x0001` | 40002 | **Measurement window** | ms | 100–60000 | 1000 | yes |
| `0x0002` | 40003 | **Averaging window** | s | 1–600, and `40003 × 1000 ≥ 40002` | 10 | yes |
| `0x0003` | 40004 | **Full travel** between the calibration points | 0.1 mm | 1–65534 | 10000 | yes |
| `0x0004` | 40005 | Raw code with window **closed** | counts | 0–65534, and `|40006 − 40005| ≥ 64` | 0 | yes |
| `0x0005` | 40006 | Raw code with window **open** | counts | 1–65535, same rule | 1023 | yes |
| `0x0006` | 40007 | **Teach command** | — | 0 idle/abort, 1 arm | 0 | **no** — reads 0 after every reset |

**40006 may legally be less than 40005.** That is how a sensor mounted so the
raw code *falls* as the window opens is expressed. The device handles both
senses; the controller need not care (FR-E04).

### 3.3 Status register 30006 — bit definitions (FR-S33, normative)

| Bit | Mask | Set while… | Class | § |
|---|---|---|---|---|
| 0 | `0x0001` | no measurement window has completed since reset or since the last write to 40002 | **startup gate** | §4.4 |
| 1 | `0x0002` | the averaging accumulator has not filled since reset or since a write to 40002–40006 | startup gate | §4.4 |
| 2 | `0x0004` | **wiper fault** — the position sensor's wiper is open | **alarm** | §7.1 |
| 3 | `0x0008` | **end of travel reached** — exactly one end sensor active | state | §5 |
| 4 | `0x0010` | **end-switch loop fault** — both end sensors active at once | **alarm** | §7.1 |
| 5 | `0x0020` | teach in progress | state | §6 |
| 6 | `0x0040` | **implausible raw code** — position outside anything the window can reach | health | §7.2 |
| 7 | `0x0080` | **position not following the carriage** — the switches saw movement, the position did not | health | §7.2 |
| 8–15 | — | always 0 | — | — |

---

## 4. Polling for the opening distance

### 4.1 Which register, for which purpose

| The controller wants… | Read | Why this one |
|---|---|---|
| A value to **position against** (closed loop, FR-WP09/FR-WP12) | **30001** | Instantaneous; never older than one measurement window (§4.2). No filtering to lag behind the actuator |
| A value that **ignores wind sway** (FR-WP21) | **30002** | Boxcar mean over 40003 seconds. With 40003 = 1 it is a 1 s mean with ≈0.45 s group delay, meeting FR-WP09 |
| **How much the leaf is moving** in the wind | **30003 / 30004** | Min and max over the same averaging window — the sway envelope, without polling at window rate (FR-E08) |
| A **percentage**, without dividing by the travel | **30015** | `(30001 − 40001) × 1000 / 40004`, 0–1000 = 0–100.0 %. Tracks 30001 exactly (FR-E20) |
| **Is it moving, and which way** | **30012** | Signed rate in 0.1 mm/s. **Decode as `int16`** — read unsigned, a closing window shows ≈65 000 (FR-E10) |

All position registers are in **0.1 mm** relative to the *closed* calibration
point plus 40001. The target 1.5 m window reads 0–15 000. The value is clamped to
`[40001, 40001 + 40004]`; the leaf may physically travel beyond the sensors
(§5.3) and the reading simply holds at the end value while it does (FR-E04).

### 4.2 Freshness — a number the controller sets, not a hope (FR-E17)

The value in 30001 at the instant a read is served is **never older than
40002 milliseconds**. The same bound applies to 30005 and 30015. There is no
"trigger a sample" command and no need for one: the controller bounds
staleness purely by configuring 40002.

| 40002 | Update rate | Max age of 30001 | Use |
|---|---|---|---|
| 100 | 10 Hz | 100 ms | only for a fast actuator. On the target window the leaf moves <1 ADC count per update at this rate (§8.1) |
| **500** | 2 Hz | 500 ms | **the target window, polled at 1 Hz** — fresh every poll (FR-WP08), 4.4 mm of staleness on a 1.5 m stroke, 0.29 % |
| 1000 (default) | 1 Hz | 1 s | the target window polled at ≤0.5 Hz — 8.8 mm, 0.58 % |
| 5000 | 0.2 Hz | 5 s | slow logging |

One exception: during the 2 s fault-hold grace after a wiper fault (§7.1), the
last valid opening is deliberately held and may be up to 2 s older. **30011 is
non-zero throughout**, so the controller can see it (FR-E17, FR-S36).

### 4.3 Coherence — one request, one snapshot (FR-S24, FR-WP12)

Every register in a single FC04 response comes from **the same measurement
update**. In particular 30001 and 30005 in one response always agree — the
controller will never see a position from one window and its raw code from
the next. **Read the registers the control loop needs in one FC04**, and the
snapshot is atomic with respect to motion for free.

**The recommended poll is a single FC04 of all 15 input registers**
(`0x0000`, quantity 15 — 30 data bytes). It costs ~35 ms of bus time at
9600 baud, is served in ~4 ms, delivers position, envelope, rate, every status
bit and every diagnostic atomically, and — as §6.3 explains — is exactly the
read that completes a teach.

### 4.4 The startup gate — bits 0 and 1

After any reset the position registers read **0** until the first measurement
window completes, and **bit 0 is set** for as long as that is true (FR-S23).
Zero is a legal opening, so **the controller must check bit 0 before
believing a position of 0.** Bit 0 also re-asserts after every write to 40002.

Bit 1 says the averaging accumulator has not filled. While it is set, 30002 is
the mean over only the samples collected so far — a real partial mean, not
zero-padded — so it is *usable*, just not yet over the full span (FR-S23).
Bit 1 re-asserts after any write to 40002–40006 and after a teach commits.

### 4.5 The fault sentinel — 65535

When the wiper is open for more than 2 s, **30001–30004 and 30015 all read
65535** and bit 2 is set (FR-E07). 65535 is outside the legal range of every
position register (max 65534), so it is unambiguous in-band — but the
controller should test **bit 2**, not the value, because bit 2 sets at the
same moment and reads cleanly regardless of which registers were requested.

### 4.6 Rate-of-change plausibility (FR-WP20)

The controller's jump-rejection rule is supported directly by 30012: any
|30012| well beyond the actuator's known speed is a reading to distrust. Rate is
computed from the last two completed windows, so it needs two windows of
movement before it is valid.

**Do not use the study's 0.58 %/s figure as the limit itself.** It *is* this
window's normal speed: 1.5 m in 171 s = 8.77 mm/s = **0.585 %/s**. A limit
placed at nominal has zero margin — the first quantisation step or a slightly
brisk actuator trips it. 30012 reads **±88** during a healthy traverse (±37 of
quantisation at 40002 = 500, so up to ±125 on a legitimate reading). Set the
limit at **|30012| > 175** (17.5 mm/s, twice nominal); the arithmetic is in
§8.1.

---

## 5. End switches

### 5.1 What the sensor reports

Two proximity sensors, one at each end of the *opening range* (§5.3), are read
through one supervised analogue input. The result is two status bits:

| Bit 3 | Bit 4 | Classification | Meaning for the controller |
|---|---|---|---|
| 0 | 0 | *neither active* | The leaf is somewhere between the stops — **or** a sensor cable is open (§5.4) |
| **1** | 0 | *one active* | **The leaf is at an end stop.** Which end: read the position (§5.2) |
| 0 | **1** | *both active* | **Fault.** Both sensors made at once — impossible on a healthy installation |

The state is debounced: a change is published only after 20 ms of stability,
so a controller polling at 50 ms never sees a bounce (FR-E15). The
classification runs at ≥10 Hz independently of the position path and of the
Modbus response time (FR-E14).

### 5.2 Which end? — the position says (deliberate design)

The switch input tells the device *that* a stop was reached, not *which*. It
spends its resolution on supervision instead. **The controller decides which
end from the position**: bit 3 set with 30001 near 0 is the closed stop; with
30001 near 40004 it is the open stop. This is also how the device itself
decides for the teach (§6.2), using direction of travel.

### 5.3 What bit 3 means — and the one thing it does not (FR-WP07)

**Bit 3 reports the sensor, not the window.** It is set while the end sensor is
*active*. On an installation built to `design/description.md` §8.1 — sensor
zone long enough that the sensor stays made from first contact all the way to
where the leaf comes to rest — bit 3 set means *fully closed / fully open*,
and FR-WP07 (fully-closed distinguishable from near-closed) is met.

Where the sensor zone is **shorter than the overtravel**, the sensor triggers
as the leaf passes and releases as it continues to its mechanical stop. The
window then sits fully closed while bit 3 reads *clear*. **No firmware can
correct this.** The controller must therefore treat "bit 3 clear" as *not
proven at a stop*, never as *proven away from one*, unless the installation
has been checked:

> **Installation check the controller can run.** Drive the window fully
> closed, wait, read bit 3. It must be set and stay set with nothing touching
> the window. Repeat fully open. If either clears, the sensor zone is too
> short. This is a commissioning check, not a runtime one.

### 5.4 Known limit — a broken sensor cable is invisible (FR-E16)

The end sensors are PNP normally-open. An inactive sensor, an open cable and a
signal shorted to 0 V all read identically: *neither active*. **The device
cannot detect a disconnected or shorted end-sensor cable and must not be
documented as if it can.** Bit 4 covers *both active at once* and nothing
else.

The consequence: if an end sensor's cable fails, the controller sees a window
that **never reaches a stop**. The health check in §7.2 (bit 7) will not fire
either, because it needs the switches to witness movement. The controller's
own cross-check is the defence — a window commanded closed, whose position
reads 0 and whose rate has been 0 for the expected travel time, but whose
bit 3 never set, has a sensor problem worth reporting (FR-WP19).

### 5.5 Independence

The switch path and the position path are separate front-ends. A switch fault
never suppresses, holds or alters the reported opening; a wiper fault never
alters bits 3/4. Bits 2 and 4 may be set in any combination (FR-E16, FR-S33).

---

## 6. Teaching the end points

The device ships knowing nothing about its window. It learns the two raw codes
that correspond to *closed* and *open* — registers 40005 and 40006 — by one of
two routes. **Neither route sets the full travel (40004)**; that is a tape
measurement the installer writes by hand (§6.4).

### 6.1 Route A — manual, three writes (FR-E05)

1. Close the window. Read **30005**. Write that value to **40005**.
2. Open the window. Read **30005**. Write it to **40006**.
3. Write the measured travel, in 0.1 mm, to **40004**.

Direction does not matter — write closed to 40005 and open to 40006 whatever
the numbers do. `|40006 − 40005|` must be ≥64 or the write is refused with
exception 03 (§8). All three can go in one FC16 to `0x0003`, quantity 3
(worked example in §10).
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

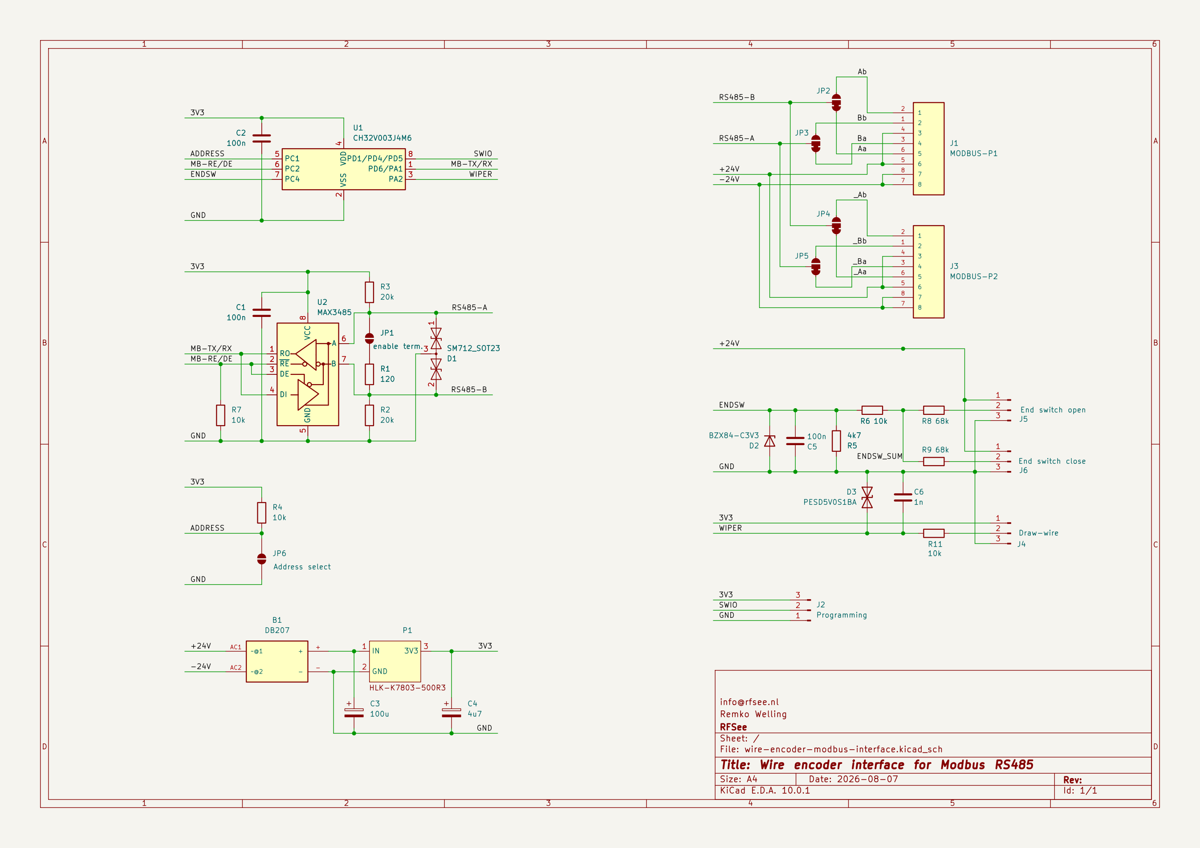
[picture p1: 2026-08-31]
hardware/Documentation/schematic/wire-encoder-modbus-interface.png

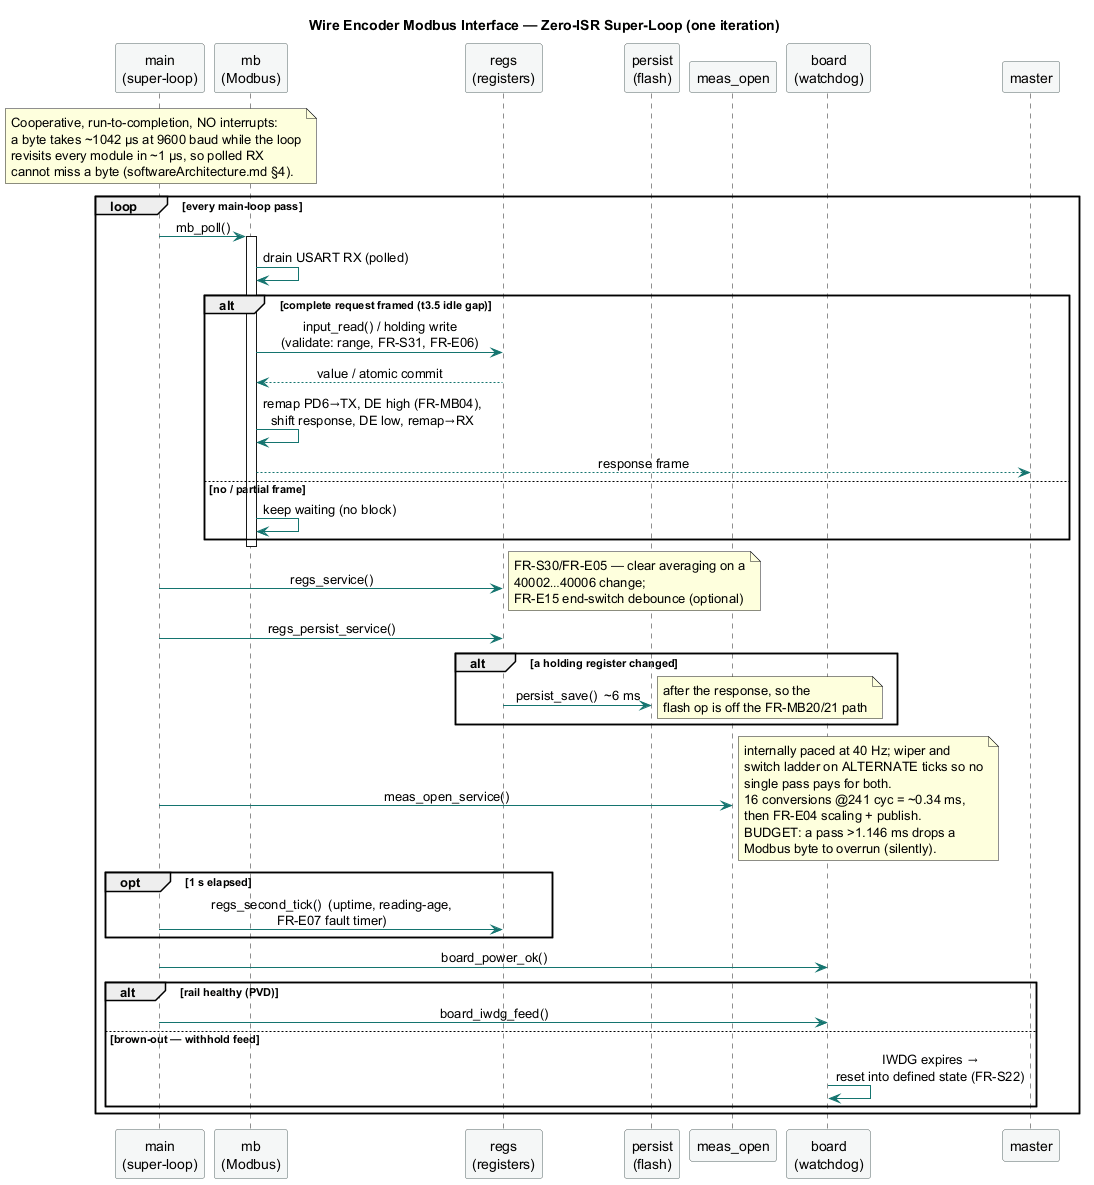
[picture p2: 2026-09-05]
design/diagrams/superloop_sequence.png

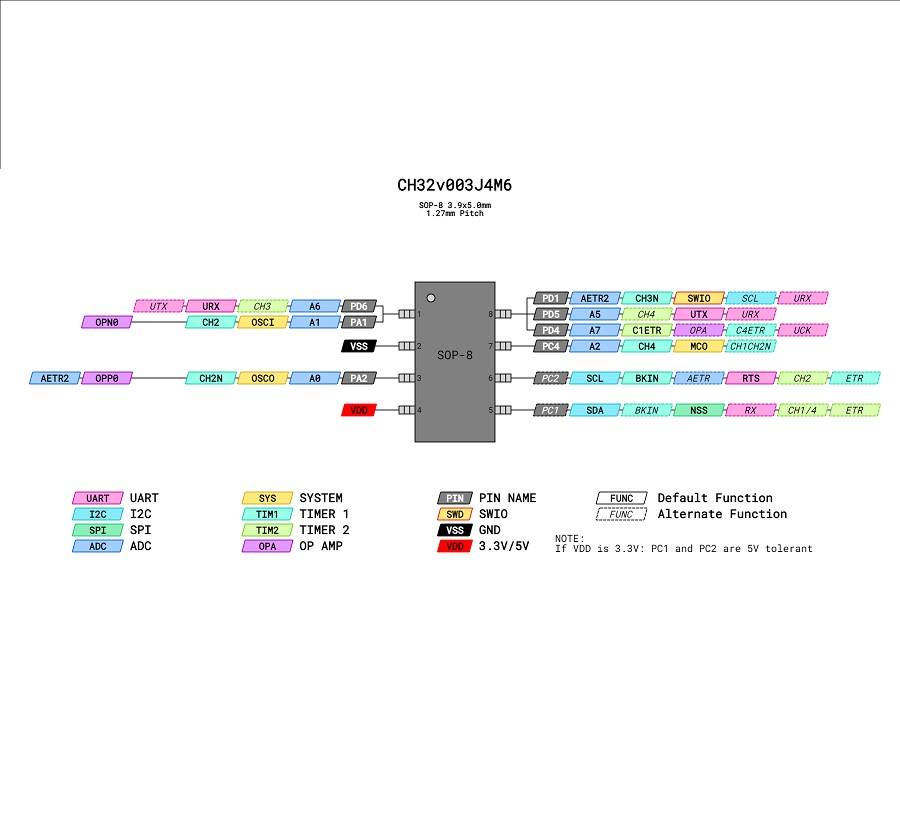
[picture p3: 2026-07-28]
documentation/CH32V003J4M6-Pinout.jpg

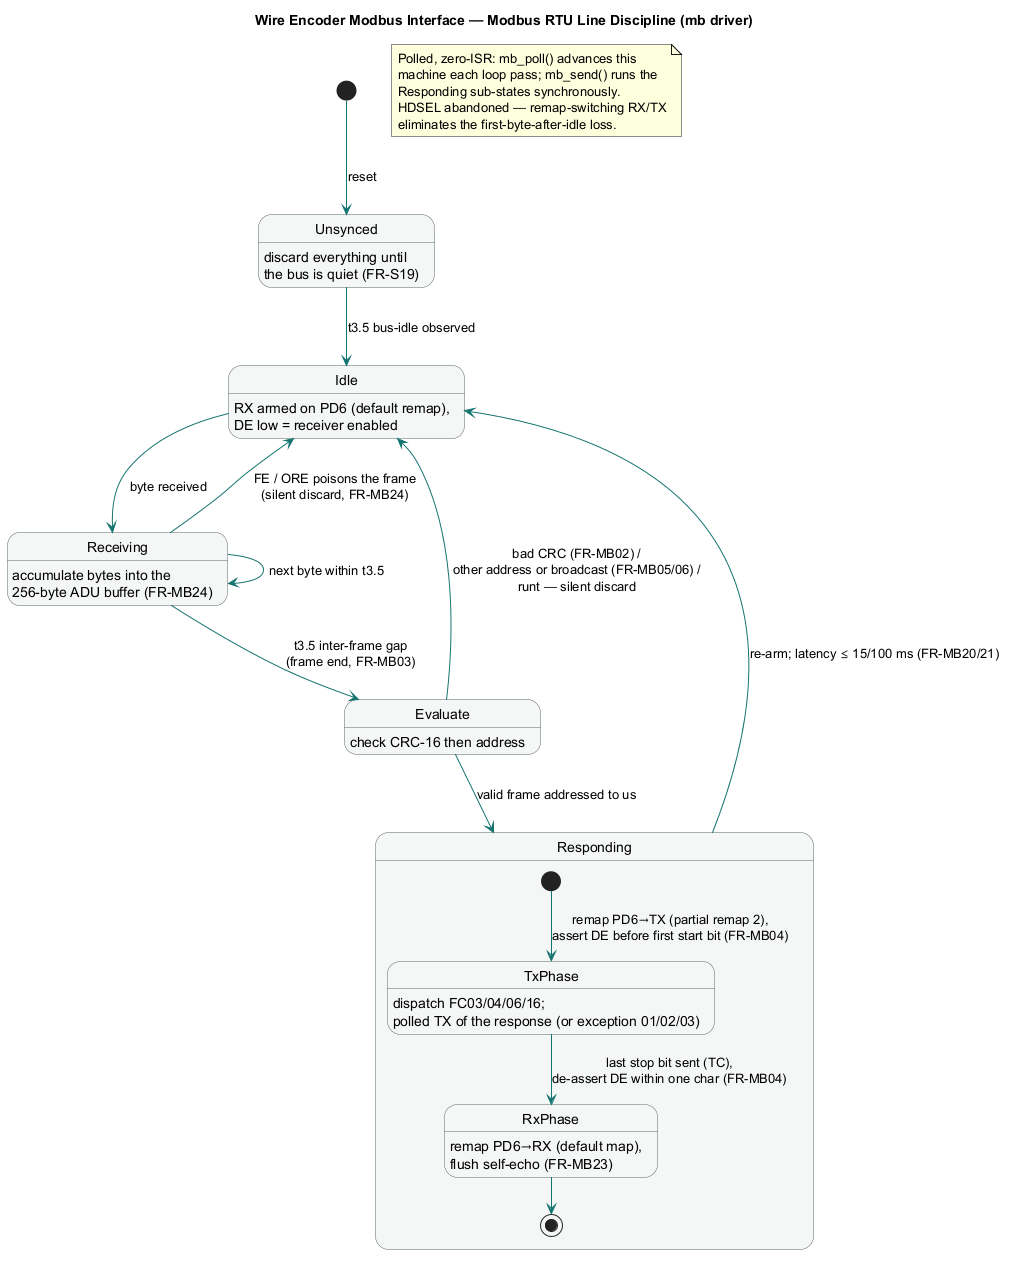
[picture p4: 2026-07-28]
design/diagrams/modbus_state.png

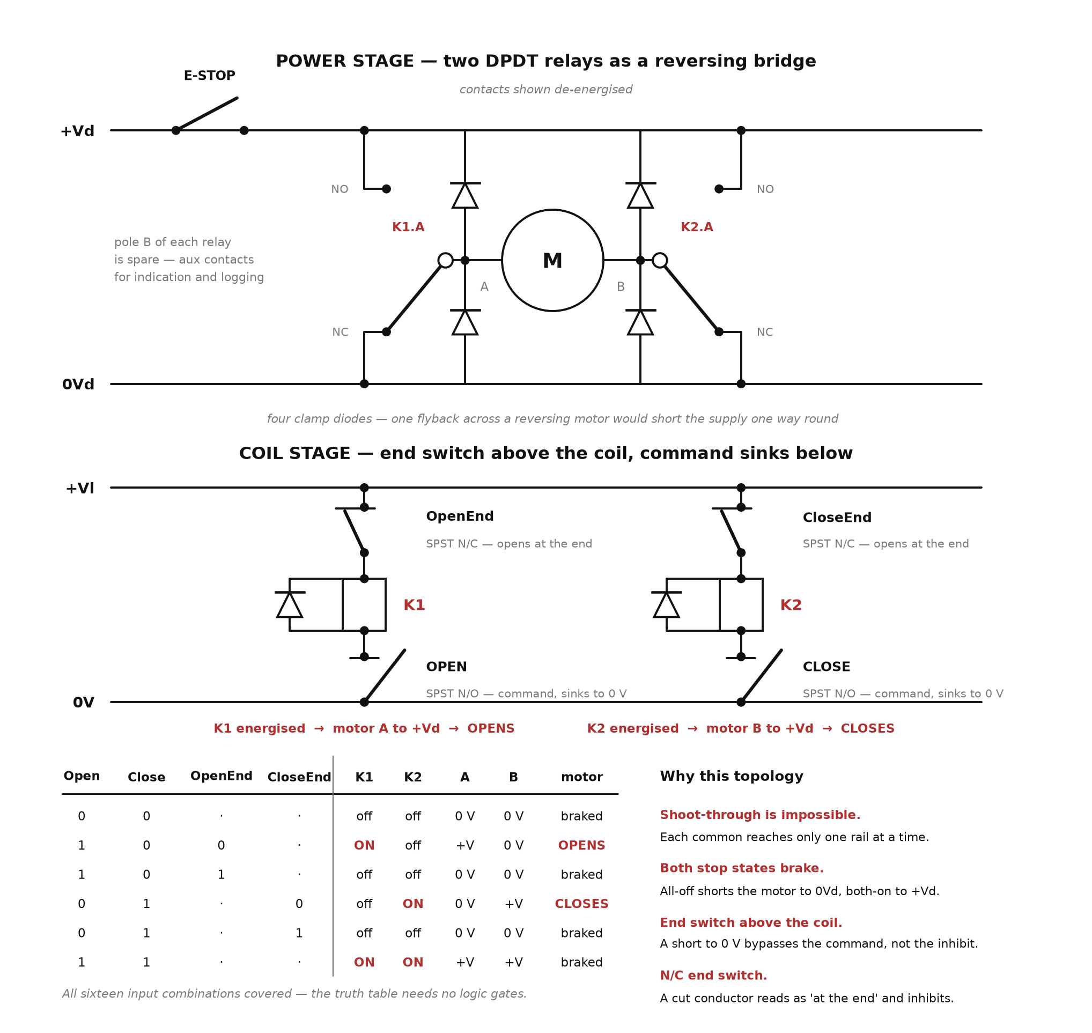
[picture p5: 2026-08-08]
design/diagrams/windowEmulatorController.png

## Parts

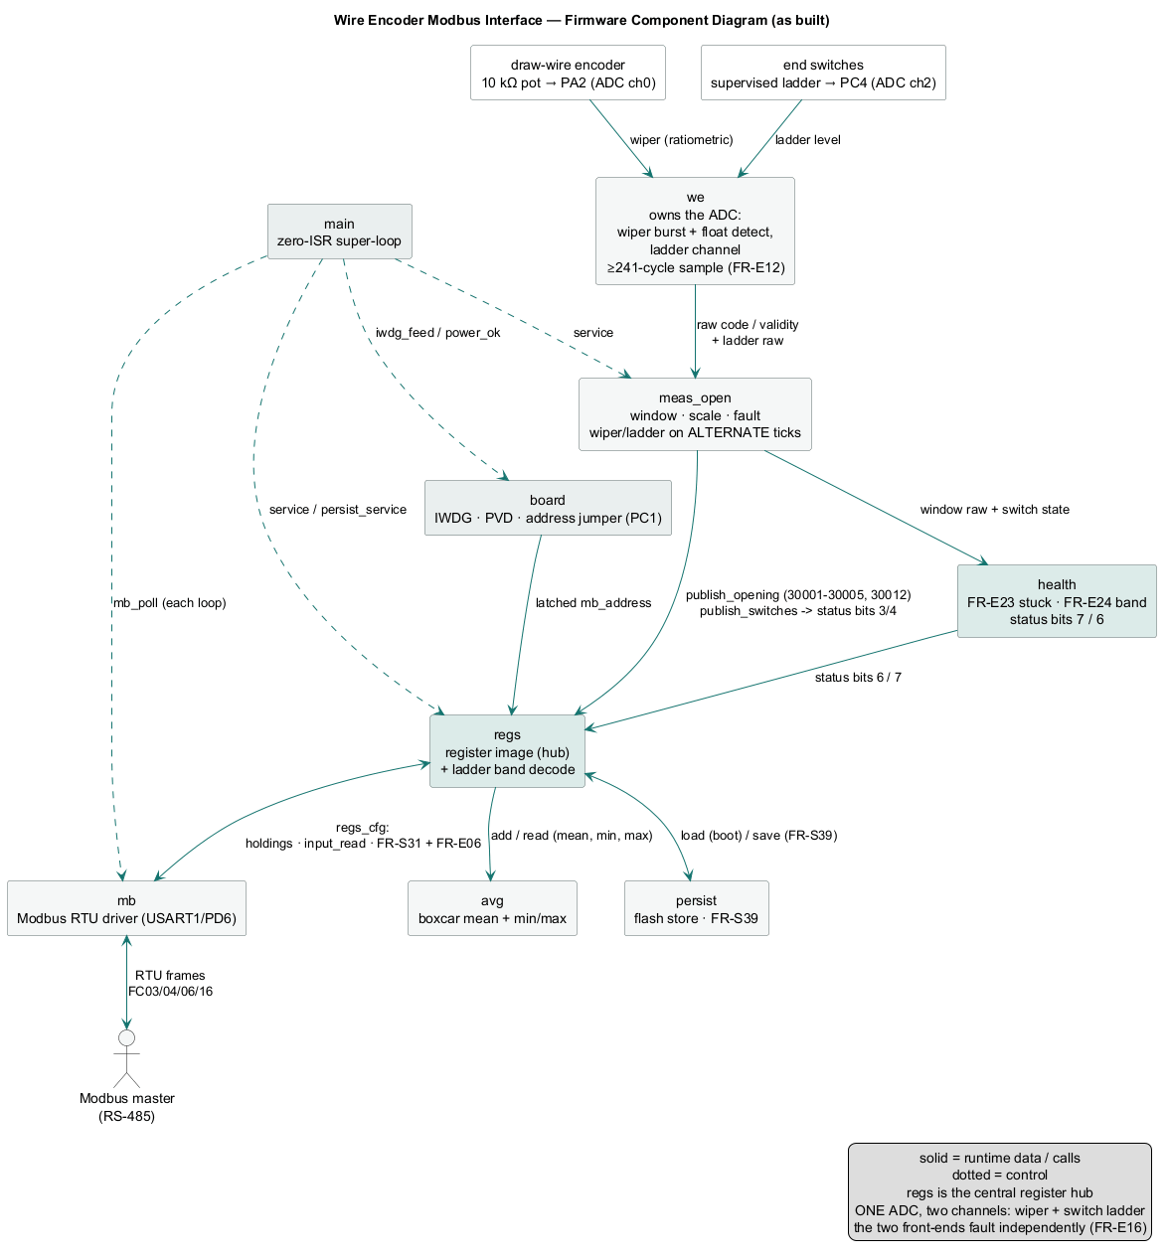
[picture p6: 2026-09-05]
design/diagrams/component.png

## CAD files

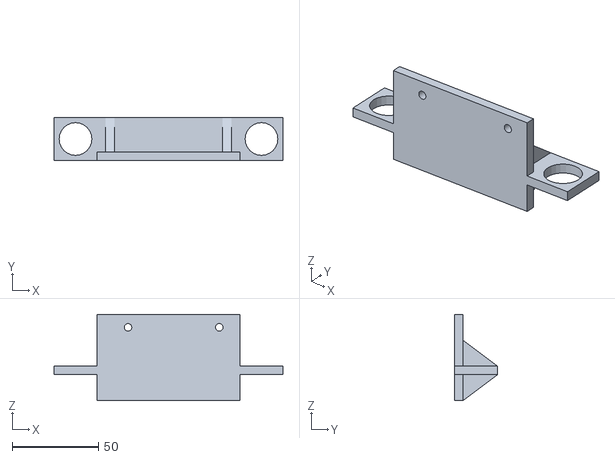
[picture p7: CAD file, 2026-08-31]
design/sensorSupport_001.stl
133.0 x 25.0 x 50.0

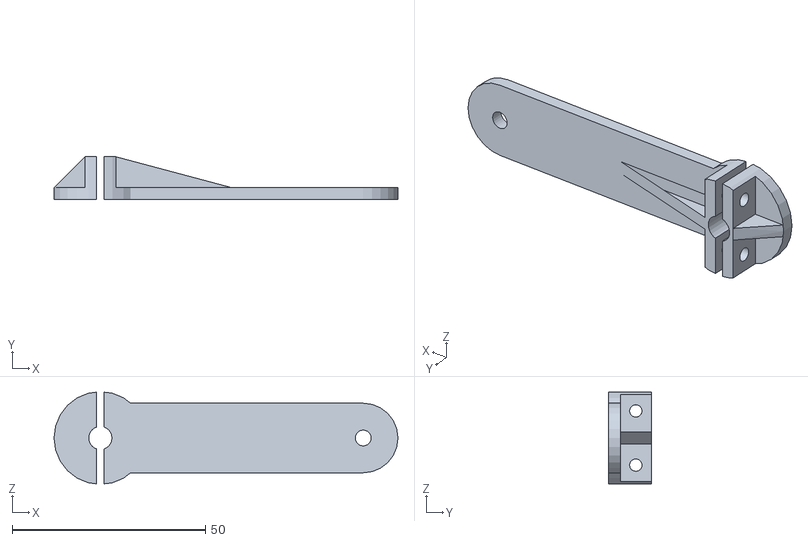
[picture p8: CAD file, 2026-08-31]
design/sensorArm_001.stl
89.0 x 11.0 x 23.7

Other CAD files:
design/sensorArm_001.skp
design/sensorSupport_001.skp
hardware/pcbOutline_001.skp

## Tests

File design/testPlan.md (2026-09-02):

# Test Plan — Hardware Verification

| | |
|---|---|
| Document | Test plan for the wire-encoder Modbus interface |
| Version | 0.3 (2026-09-01 — Group C gained TP-C01/TP-C02 for FR-E23/FR-E24; every requirement family is now gate-checked by `test_traceability.py`, not just FR-MB) |
| Traces to | [`TDS.md`](TDS.md) v0.7 — every row below cites the requirement whose verification clause it executes |
| Records to | [`../software/hil/testReport.md`](../software/hil/testReport.md) |
| Supersedes | [`integrationPlan.md`](integrationPlan.md) §7, which was a placeholder awaiting hardware |

---

## 1. How to use this

Every row traces to a requirement in [`TDS.md`](TDS.md). The requirement owns
the pass criterion; this document owns the *procedure* — what to connect, what
to do, and in what order. Where the two disagree, **the TDS wins** and this
plan is wrong.

Do not tick a row off without writing the observed value into
`software/hil/testReport.md`. A row recorded as "pass" with no number is worth
very little six months later, and this project has already had two occasions
where a computed figure turned out to be wrong by a factor of three.

**Run the groups in order.** Group A needs no firmware and includes the one
measurement currently blocking the PCB. Group B needs a flashed device and is
the largest body of work that the *current* image can actually satisfy.

---

## 2. What this plan cannot cover yet, and why

`regs_publish_switches()` and `regs_publish_opening()` exist and compile, but
**`main.c` never calls them** — they sit behind stage-D comments. In the image
you can flash today, the measurement path and the end-switch classification are
dead code.

That is not a wiring problem and no amount of bench work fixes it. It means:

| | Rows | Status |
|---|---|---|
| **Group A** — electrical, no firmware | 9 | **Runnable now** |
| **Group B** — protocol and lifecycle | 36 | **Runnable now**, on a flashed device (TP-B36 excepted — it needs a PCB) |
| **Group C** — measurement, switches, teach | 26 | **Blocked** until integration stage D |
| **Group D** — environmental | 5 | Needs a climate chamber |
| **Group E** — build-time | 3 | Already automated in `software/hil/acceptance/` |

Group C is not deferred by choice. Attempting those rows against the current
image will produce failures that mean nothing.

---

## 3. Equipment and setup

| Item | Purpose | Status |
|---|---|---|
| WCH-LinkE | Flash and debug over SWIO | **Verified working** 2026-08-31 — `mode:RV version 2.15`, target examined, `misa=0x40800014` |
| Bench PSU, 24 V, adjustable ±15 % | Sensor supply and PoE feed; Group A and the tolerance rows | Required |
| DMM, 4½ digit | Node voltages; 1 mV resolution matters for the §4.4 bands | Required |
| **ADALM2000 (M2K)** | Stimulus *and* the raw RS-485 master — see §3.2. Also a 16-channel logic analyser, so it covers the timing rows until the Saleae arrives | **Available.** `libm2k` in a Python 3.11 venv; `m2k_smoke.py` proves the link |
| Saleae Logic16 | Preferred observer for the FR-MB timing rows | **Connected and verified** 2026-09-01 — device `94BAD48182A91BFD` visible over the Logic 2 MCP bridge. Probe map in §3.5 |
| Hot-air source or hair dryer | TP-A01, the blocking leakage test | Required |
| Precision resistance box or 10 k pot | Stands in for the draw-wire in Group C | For stage D |

### 3.1 DUT configuration

**The DUT is a breadboard build — there is no PCB.** That is not a caveat to
apologise for; it is the correct order, because TP-A01 gates the layout. But
it changes what some rows mean:

- **Every node is accessible.** No test points needed, no clip-to-SOIC-pin.
- **The rig is now a suspect.** A breadboard has its own leakage and its own
  intermittent contacts, and both can masquerade as device behaviour. TP-A00
  exists because of this.
- **The wiper node is the vulnerable one.** §4.6 requires >10 MΩ from that
  node to any rail, and a used breadboard with flux or finger grease across a
  few rows can be far below that. Long jumpers on a 2.5 kΩ node also pick up
  noise that a ground-planed PCB would not. Expect the wiper to look worse
  here than it will on a board — and do not tune anything to compensate.
- **Contact intermittency looks exactly like a sensor fault.** Before
  believing any FR-E07 or switch-band anomaly, reseat and re-measure.

- **Build:** `encoder` (build byte `0x01`) for everything except TP-B21/B22,
  which need `encoder_test` for the FR-S20 hang hook.
- **Address:** 40 with the PC1 jumper open, 45 bridged. 9600 8N1.
- **Never ship `encoder_test`** — `platformio.ini` says so and it carries the
  watchdog hang trigger at holding `0x00FF`.

### 3.2 The M2K raw master — how Group B gets driven

There is no USB Modbus adapter in this plan and none is needed. The sibling
project's rig, documented in [`../software/hil/README.md`](../software/hil/README.md),
drives a **second MAX3485 as a raw master** from the M2K:

```
M2K DIO0 ──► DI          second MAX3485        A/B ──► DUT bus
M2K DIO1 ──► DE + R̄Ē     (the raw master)      A/B ──► M2K scope 1+/2+
M2K V+   ──► VCC (3.3 V)
```

Bit-banging the master this way is *better* than a USB adapter for this plan,
not a workaround: it gives exact control of inter-frame timing, which is what
FR-MB20/21/23 actually test. A USB adapter hides precisely the thing under
test behind its own driver's buffering.

Four inherited lessons, each of which cost someone an afternoon:

- **Enable V+ in every script.** `ps.enableChannel(0, True)` then
  `pushChannel(0, 3.3)`. An unpowered MAX3485 sits inert and looks exactly
  like a wiring fault. The static DE/DI test — drive space, drive mark,
  release — is the ten-second proof the rig is alive.
- **A listening master never stops buffering.** It accumulates every byte
  another node puts on the shared bus, then parses the stale backlog and
  reports CRC_ERR. One throwaway read *is* the flush; retry once on
  `crc_error` before trusting a read that follows raw-master traffic.
- **Inter-frame marks must exceed t3.5 = 4.01 ms** at 9600 baud. A 2.5 ms gap
  once made the DUT correctly coalesce two frames into one discarded frame.
  The house gap is **5 ms** (48 bit times).
- **Keep M2K AWG outputs 0–3.3 V** near the DUT. The hardware can swing ±5 V,
  which is beyond CH32V003 absolute maximums.

All grounds common — M2K, Saleae, LinkE and DUT.

### 3.3 Two M2K limits that bite this plan specifically

- **Scope inputs are ±25 V.** The +15 % supply case is **27.6 V and exceeds
  them.** TP-A03 and TP-A08 must be measured with the DMM, not the M2K scope.
- **The M2K supplies are ±5 V at ~50 mA** and cannot feed the 24 V rail at
  all — two sensors alone draw 20 mA at 24 V. The bench PSU owns that rail.

### 3.4 Programming power rule — read before connecting

The SOP-8 package has **no NRST**, so power-cycling is the only recovery path
from a wedged debug interface. J2 pin 3 carries 3V3, and so does the board.

> **Either** remove the 24 V feed and let the LinkE supply 3V3 through J2,
> **or** keep the 24 V feed and leave the LinkE's 3V3 disconnected.
> Never both, and never neither.

Getting this wrong parallels two supplies *and* removes the LinkE's ability to
power-cycle the target — precisely when you would need it.

### 3.5 Probe map

Four digital channels tell the whole Modbus story: what the master sent, when
it released the bus, what the DUT saw, and when the DUT drove. Ground common
throughout; Saleae threshold set for **3.3 V logic**.

| Ch | Signal | Connect to | Gives you |
|---|---|---|---|
| **0** | `MB-TX/RX` | **U2 pin 1 or 4** (= U1 pin 1) | Both directions of the conversation — RO and DI are tied for half-duplex. Decode as **UART 9600 8N1**. |
| **1** | `MB-RE/DE` | **U2 pin 2 or 3** (= U1 pin 6) | When the DUT takes and releases the bus — TP-B14 and TP-B24. |
| **2** | raw-master `DI` | **M2K DIO0** | What the master actually put on the wire. |
| **3** | raw-master `DE/RE` | **M2K DIO1** | When the master released. Paired with ch 1 this measures t3.5 directly. |
| GND | — | **U2 pin 5** or **J2 pin 1** | J2 is a 2.54 mm header and is the tidiest ground tap. |

**The Saleae cannot be driven end-to-end from the MCP bridge.** `start_capture`
requires a `logicDeviceConfiguration`, but a Logic16's input voltage range
cannot be set through it — the schema accepts only 1.2 / 1.8 / 3.3 and the
backend rejects all three, wanting a range (`1.8V to 3.6V`, `3.6V to 5.0V`).
Omitting it starts a capture whose default range does not match 3.3 V logic and
which records **no transitions at all**. Capture Saleae rows from the Logic 2
UI and load the `.sal` afterwards.

`U2` is the MAX3485 in SOIC-8, easier to reach than the MCU's SOP-8 — though
on the breadboard either is a jumper away.

**Do not put the Saleae on RS-485 A/B.** They are differential and idle only
**258 mV** apart on the 680 Ω fail-safe bias (the 120 Ω termination was removed
and the original 20 k bias pair replaced — see the test report); a digital
threshold there yields frame boundaries at best. **A/B → M2K scope 1+/2+** for
the analog wire view. The split is deliberate: Saleae observes logic, M2K
observes the line.

For the programming interface rather than the bus, probe `SWIO` on **J2 pin 2**
(or U1 pin 8) with ground on **J2 pin 1**.

#### Reference pinouts

| U2 — MAX3485 | | U1 — CH32V003J4M6 | | J2 |
|---|---|---|---|---|
| 1 `RO` → MB-TX/RX | 5 `GND` | 1 `PD6/PA1` MB-TX/RX | 5 `PC1` ADDRESS | 1 `GND` |
| 2 `R̄Ē` → MB-RE/DE | 6 `A` | 2 `VSS` | 6 `PC2` MB-RE/DE | 2 `SWIO` |
| 3 `DE` → MB-RE/DE | 7 `B` | 3 `PA2` WIPER | 7 `PC4` ENDSW | 3 `3V3` |
| 4 `DI` → MB-TX/RX | 8 `VCC` | 4 `VDD` | 8 `PD1` SWIO | |

---

## 4. Group A — electrical, no firmware required

Run these first. TP-A01 is the item gating the PCB.

| ID | Traces to | Procedure | Pass criterion |
|---|---|---|---|
| **TP-A00** | §4.4.4 | **Run this before TP-A01.** Verify the rig before trusting any reading from it: R5 continuity to 0 V, R6 to the summing node, R10 **absent**. Then unplug both sensor outputs from R8/R9 and measure PC4. | **≤ 5 counts (≈0.016 V).** *(Executed 2026-08-31 — **FOUND TWO FAULTS**: R10 still fitted and R5 floating. Every measurement taken before the fix was of a circuit that was neither the schematic nor a divider, and all of it was discarded. This row earned its place on first use — and again afterwards, when its own criterion caught the MCU pull-up on PC4 that had survived every rig fix. Passed on the fourth attempt at −20 mV.)* |
| ~~**TP-A01**~~ | TDS §6, §4.4.4 | **WITHDRAWN 2026-08-31 — there is no leakage to heat.** The 33 µA it was written to characterise was the MCU's pull-up on PC4, not the sensors, which move PC4 by 0.9 mV between connected and disconnected. Retained here only so the withdrawal is visible. Original procedure: Disconnect sensor B. With sensor A powered and inactive, record PC4 at room temperature. Warm the sensor body by ~20 °C (hot air, low; measure the case). Record PC4 every 5 °C. | PC4 rises by **less than 30 %** over the sweep → the 35 µA is an internal bleeder, §4.4 stands. A steep climb → junction leakage, and §4.4.2's values need re-deriving with a smaller `Rs` and a lighter load. **Record the curve, not just the verdict.** |
| **TP-A02** | §4.4.3 | With both sensors connected and powered, measure PC4 in all three states: neither active, each one active separately, both active. | Within **±5 %** of −0.019 / 1.291 / 2.210 V. *(Executed 2026-08-31, final set: −0.019 / 1.291 / 1.292 / 2.210. `Von` = 23.09 V from three independent routes agreeing to 0.2 %.)* |
| **TP-A03** | §4.4.4 | Sweep the sensor supply 20.4 → 27.6 V. Record PC4 for one-active and both-active at each end. | One active ≤ 462 counts and both active ≥ 582 counts, i.e. the 522 threshold is not crossed from either side. **BLOCKED 2026-08-31 — no adjustable PSU available.** This matters more than a skipped row usually would: the ±15 % supply margin is the *tightest number in the design* (≈60 counts at `SW_TH_BOTH`) and it is currently **calculated, not measured**. It also leaves open whether the 1.01 V output drop is constant or scales with the rail, which is what the sweep would have settled. Needs a bench supply, or a series element to drop the rail for the low end. |
| **TP-A04** | FR-E21 | Apply **+27.6 V** to each J4 pin in turn for 60 s. Measure the current into PA2. | ≤ **4 mA** (CH32V003 absolute maximum, datasheet §3.2). Device undamaged; the wiper reads correctly after removal. |
| **TP-A05** | FR-E21, §4.6.1 | Measure the mid-scale wiper code with D3 fitted and unfitted, at room temperature and at +70 °C. | Difference ≤ **1 count**. This is the PESD5V0S1BA leakage figure no datasheet answers at 3.3 V and +70 °C. |
| **TP-A06** | §4.3, FR-E11 | With the draw-wire at mid-travel, verify the wiper is fed from 3V3 and that PA2 tracks it ratiometrically: vary 3V3 by ±5 % and observe the *ratio*. | The wiper/3V3 ratio changes by < 0.2 %. Confirms nothing has broken ratiometric operation. |
| **TP-A07** | §4.6 | Measure insulation from the wiper node to each rail, board clean and dry. | > **10 MΩ** — the §4.6 rule. Below that, conformal coating is not optional and the board is already out of budget. |
| **TP-A08** | §4.1 | Measure the 3V3 rail and total board current at 20.4 / 24 / 27.6 V input. | 3V3 within 3.1–3.4 V at all three. Record the current for the PoE budget. |
| **TP-A09** | §4.4 | Confirm both sensors are wired **star** — one cable each to the hub, summing on the PCB — and that R10 is absent. | Visual against the §4.4.2 schematic. A field junction here would invalidate every Group C switch row. |

---

## 5. Group B — protocol and lifecycle, on a flashed device

Everything here works against the **current** image. This is the largest body
of verification available before stage D, and none of it needs the measurement
path.

### 5.1 Boot and identity

| ID | Traces to | Procedure | Pass criterion |
|---|---|---|---|
| TP-B01 | FR-S32 | Power on. Poll 30007 (identification). | Reports build byte `0x01` and the firmware version, identical with the jumper open and bridged. |
| TP-B01b | FR-S01, FR-S32 | Read 30007 and check the **high bit of the build byte**. | `0x01vv` = release image; `0x81vv` = a bench build carrying the FR-S20 hang hook. **Verified 2026-09-01**: `encoder` reports `0x0101`, `encoder_test` reports `0x8101`. The holding-`0x00FF` probe is retained as a cross-check, not as the primary means. |
| TP-B36 | FR-S02 | Flash the release binary onto an **unmodified PCB** — no cuts, no bodge wires, no hand-fitted parts — and run the full §2/§3 acceptance suite. | The suite passes with no hardware modification. **BLOCKED: no PCB exists**; everything to date is a breadboard. This is what FR-S02 actually requires, and it went untested because TP-B03 cited it for boot timing instead. |
| TP-B02 | FR-S03, FR-MB07 | Read the device at address 40 with JP6 open. Power down, bridge JP6, power up, read at 45. | Responds only at the expected address in each case. Changing the jumper while running has **no** effect until reset. |
| TP-B04 | FR-S32 | Read 30007 across a power cycle. | Identical both times. |
| TP-B05 | FR-S34 | Read 30008 (uptime) at intervals over 10 min. | Monotonic, whole seconds, starts at 0 after reset. |

### 5.2 Modbus contract — FR-MB01…FR-MB30

The full protocol row set is inherited from the sibling project's TDS v0.9,
where every row is HIL-verified against the same driver binary. Re-run rather
than assume: the address, the register map and the build differ.

| ID | Traces to | Procedure | Pass criterion |
|---|---|---|---|
| TP-B06 | FR-MB01, FR-MB08, FR-MB09, FR-MB10, FR-MB11 | FC03, FC04, FC06, FC16 against valid addresses. | Correct data, correct byte count, correct CRC. |
| TP-B07 | FR-MB25 | Inspect data byte order and CRC byte order on the wire. | **Big-endian data, little-endian CRC.** |
| TP-B08 | FR-MB19 | Write out-of-range values to each holding register (below min, above max). | Exception code 3; the stored value is unchanged. |
| TP-B09 | FR-MB22 | FC16 spanning 40002 and 40003 such that the pair is valid but each intermediate state is not. | Accepted — atomicity judged on the result, not the intermediate. |
| TP-B10 | FR-E06 | FC16 writing 40005/40006 closer than `CAL_MIN_SPAN` (64 counts). | Rejected, both values unchanged. |
| TP-B11 | FR-MB05, FR-MB06 | Frame addressed to another device (247); broadcast frame (address 0) carrying a write whose effect is observable. | Silence for both. The broadcast must **not be executed** — a follow-up unicast read shows the register unchanged. This is a deliberate deviation from Modbus-over-Serial-Line V1.02 §2.2, stated in FR-MB06; the pass criterion is *not* the specification's. |
| TP-B12 | FR-MB02, FR-S35 | Frame with a deliberately bad CRC. | No response within 200 ms; **30009 increments by exactly one** and 30010 does not move. |
| TP-B13 | FR-MB13 | Read a non-existent register address. | Exception code 2. |
| TP-B14 | FR-MB20 | Logic-analyser capture of turnaround and response latency across 1000 polls. | Within the FR-MB20/21 budgets; histogram recorded. |
| TP-B15 | FR-MB03 | Inter-frame idle (t3.5) at 9600 baud. | Frames separated correctly; no merged frames under back-to-back polling. |
| TP-B16 | FR-S35 | Read 30009 and 30010 after a known mix of good and bad frames. | Counts match the frames sent exactly. |
| TP-B17 | §2.7, FR-MB08, FR-MB27 | Read every input register 30001–30015. | All present; measurement registers return their FR-S23 pre-first-window value (see §6 — this is expected, not a fault). |
| TP-B18 | §2.8, FR-MB09 | Read every holding register 40001–40007 after a factory reset. | Defaults match §2.8: 0 / 1000 / 10 / 10000 / 0 / 1023 / 0. **Precondition:** no factory-reset procedure is defined yet (see §7), so a run that merely finds the defaults present has not verified them. |
| TP-B25 | FR-MB12 | Send FC01, FC02, FC05 to the DUT's address. | Exception **01** for each. |
| TP-B26 | FR-MB14 | FC04 read whose range spans the map edge (e.g. 12 registers from 30010). | Exception **02** for the whole request; **no partial data**. |
| TP-B27 | FR-MB15 | FC06 write to an unimplemented holding address (raw 0x0020). | Exception **02**; no register changes. |
| TP-B28 | FR-MB30 | Capture the FC06 and FC16 success responses. | FC06 response is **byte-identical** to the request. FC16 response PDU after the function code is exactly starting-address then quantity — **not** the register data. |
| TP-B29 | FR-MB21 | 1 000 FC04 requests at 50 ms spacing, default configuration. | ≥95 % of responses start within **15 ms** of the last request byte; 100 % within the FR-MB20 100 ms limit. Histogram recorded. |
| TP-B30 | FR-MB18, FR-MB29 | Collect every exception response produced across Group B. | Only codes **01, 02, 03** ever appear. No vendor-specific codes. |
| TP-B31 | FR-MB17 | Every valid addressed request issued in Group B. | The DUT is never silent on one — a normal or exception response always arrives. |
| TP-B33 | FR-MB28 | FC03/FC04 with quantity **0** and **126**; FC16 with quantity **0** and with a byte-count field ≠ 2 × quantity. | Exception **03** for each; **no register modified**. FC16 quantity **>123 is not testable** — see §9. |
| TP-B34 | FR-MB24 | Send more bytes without a t3.5 gap than the 256-byte ADU maximum; and a byte deliberately mis-framed. | Frame discarded, **no response**; the device answers the next well-formed request normally. |
| TP-B35 | FR-S16, FR-MB23 | 10 000 request/response cycles at 9600 with no external crystal fitted. | **Zero** framing/CRC errors — 30009 unchanged, 30010 advanced by exactly 10 000. Also the standing evidence for FR-MB23: a device that evaluated its own transmission as an incoming frame could not hold a zero CRC-error count across 10 000 exchanges. |
| TP-B32 | FR-MB04 | Measure the DUT's **drive envelope** on the M2K analog inputs (`tp_b32.py`) — driven is ±1.4 V, released is the 0.26 V fail-safe bias, so DE is observable from the bus without probing PC2. Sanity-check the measured drive window against the frame length before believing any margin. | DE asserted before the first start bit and released after the last stop bit, each within one character time (11 bits = **1.146 ms**). |

### 5.3 Persistence, watchdog and supply

| ID | Traces to | Procedure | Pass criterion |
|---|---|---|---|
| TP-B19 | FR-S39 | Write non-default values to all six persisted holdings. Power-cycle. Read back. | All six survive. 40007 (teach) reads **0** — deliberately not persisted. |
| TP-B20 | FR-S39 | Repeat 20 power cycles, cutting power at random points including mid-write. | No corruption; the ping-pong store always yields a valid record. **ACCEPTED 2026-09-01 at 13 of 20 cycles** — no corruption in any, several with the cut landing mid-burst. The remaining 7 were dropped by decision, not overlooked: each cycle costs ~200 flash writes and the run had already spent ~23 % of a conservative endurance budget on this board. Re-run in full on the PCB, where the flash is not a prototype's. |
| TP-B21 | FR-S20 | **`encoder_test` build.** Write magic `0xDEAD` to holding `0x00FF` to stall the loop. | IWDG resets the device within the FR-S20 timeout. |
| TP-B22 | FR-S21 | After the TP-B21 reset, read all registers. | Defined state: holdings restored from flash, measurement registers at their pre-first-window values, status bits 0 and 1 set. |
| TP-B23 | FR-S22 | Ramp the supply down slowly until PVD trips. | Device resets cleanly rather than executing at an undefined rail. |
| TP-B24 | FR-S18, FR-S19 | Capture the RS-485 bus from power-on with the analyser. | DE/RE is low (receiver enabled, driver off) from the first instant; no bus disturbance during boot. |

---
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

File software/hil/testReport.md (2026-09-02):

# HIL Test Report

Consolidated record of every hardware-in-the-loop test executed against
this project's device under test: setup, expected result, pass criteria,
and verdict.

| Field | Value |
|---|---|
| Project | `wire-encoder-modbus-interface` |
| Last updated | 2026-09-01 |
| DUT | **Breadboard build.** CH32V003J4M6, MAX3485, 3RG4023-3AB00 ×2, draw-wire front-end. No PCB. |
| Plan | [`design/testPlan.md`](../../design/testPlan.md) v0.2 |

---

## Status: stages A–F complete; acceptance suite green

Hardware exists and has been exercised. What follows is what was actually
run — everything else in the plan is still untouched.

### Executed

| Row | Date | Result |
|---|---|---|
| — | 2026-08-31 | **Debug link verified.** WCH-LinkE `mode:RV version 2.15`; target examined, `XLEN=32`, `misa=0x40800014` (RV32EC + vendor) — the expected silicon. Reached via OpenOCD, not minichlink: the `WCHLink_A64` driver blocks libusb (`LIBUSB_ERROR_ACCESS`), and `upload_protocol = wch-link` routes through OpenOCD anyway, so no Zadig/WinUSB step is needed. |
| — | 2026-08-31 | **Firmware flashed.** `encoder` build byte `0x01`, 3 704 B flash / 620 B RAM. `** Verified OK **`. |
| **TP-A00** | 2026-08-31 | **PASS, on the fourth attempt.** −20 mV with both sensor outputs disconnected. It failed three times first, and each failure was a real fault it was written to catch: **R10 still fitted**, **R5 floating**, a third wiring error, and finally **the MCU's internal pull-up on PC4** (~47 kΩ to 3V3, sourcing ~63 µA into the summing node) left enabled by the image previously in flash. |
| **TP-A02** | 2026-08-31 | **PASS.** Bands at `Von` = 23.09 V: **−0.019 V / 1.291 V / 2.210 V** = **0 / 401 / 686 counts**. `Von` confirmed by three independent routes agreeing to **0.2 %** — each switch alone, and both together (which carries no leakage term). Rail 24.1 V. |
| **TP-A01** | 2026-08-31 | **WITHDRAWN.** Written to characterise a 33 µA sensor leakage that turned out not to exist — it was the PC4 pull-up. Connecting or disconnecting both sensors moves PC4 by 0.9 mV. |
| **TP-A09** | 2026-09-01 | **PASS — visual, confirmed by the operator.** Both end sensors wired **star**, one cable each to the PCB hub, summing on the board; R10 absent. Not an instrument measurement: a field junction is invisible electrically, which is why the row exists and why it gates the Group C switch rows. |
| — | 2026-09-01 | **First Modbus transaction.** DUT answered at unit 40, 9600 8N1. `30007 = 0x0101` (build `0x01`, firmware 1) and a full 15-register FC04 read. See below. |

### Modbus link brought up

Three faults stood between a correctly flashed DUT and a first reply. Only the
first was on the DUT's side of the wire, and none of them was the DUT.

1. **No fail-safe bias — the receiver had no defined idle state.** The DUT's
   `served`, `crc_errors` and `rx_len` counters all read 0 after ten frames,
   and `GPIOD_IDR = 0xB2` put **PD6 low** — the RX line sitting at space, not
   idle mark. Idle differential measured **−0.011 V** against the ≥200 mV a
   receiver needs to resolve. Forcing DE high proved the DUT's transceiver
   drove the bus correctly, so the fault was the bias network, not the part.
   Arithmetic located it: `3.3 × RL/(40 000 + RL) = 0.011` gives RL ≈ 133 Ω,
   i.e. a ~120 Ω termination the 20 kΩ bias pair could not pull against.
   **Fix (bench):** termination removed, bias changed to 680 Ω. Idle
   differential is now **+258 mV** and the master selftest passes all three
   checks.
2. **A leading null on every reply.** With DE and R̄Ē tied on the raw master,
   RO floats while we transmit and its enable transient decodes as one spurious
   byte. Cured in software: the master now hunts for the span that starts with
   the expected unit address *and* carries a valid CRC, rather than assuming
   the first byte received is the first byte of the response.
3. **Long replies lost characters; short ones did not.** A 7-byte
   identification reply decoded perfectly while a 35-byte register read came
   back four bytes short — which reads as a truncated response and is not one.
   The capture held **61.8 ms of idle after the last edge**, so nothing was
   truncated. Run-length measurement on the RX line showed **9.92 bit times per
   character**: the DUT transmits **0.8 % fast**, well inside UART tolerance.
   The decoder was at fault — it advanced a fixed ten bit times per character
   instead of resynchronising on each start edge, so the error accumulated to a
   whole bit time across a long frame. Now resyncs per character; regression
   tests cover a 35-byte frame at ±1 % baud, including the all-zeros case where
   the stop bit is the only edge to lock to.

**Measured:** DUT UART **0.8 % fast** at 9600 (9.92 bit times per character,
960 kSa/s capture) — evidence for FR-MB01's 9600 8N1, well inside the ±5 %
a UART receiver tolerates.

**First full read**, unit 40, FC04, 15 registers:

| Register | Value | Reading |
|---|---|---|
| 30006 status | `0x0013` | bits 0+1 (no window published yet) and bit 4 (switch fail-safe until the first ladder sample) — all three correct for integration stage D being absent |
| 30007 identification | `0x0101` | build `0x01`, firmware 1 — matches `platformio.ini` and FR-S32 |
| 30008 uptime | 42 588 s | 11 h 49 m, powered since the flash |
| **30009 CRC errors** | **0** | **every frame the DUT received was well-formed** |
| 30010 served | 10 | our transactions, all answered |
| 30011 reading age | 42 588 s | nothing ever published — stage D, as expected |
| 30001–30005, 30012 | 0 | no measurement path yet |

The zero CRC-error count is the load-bearing number: it says the DUT's receive
path was correct throughout, and every symptom above was on the master's side.

### What TP-A02 established

- **Output drop is 1.01 V at 290 µA**, not zero. The datasheet's ≤2.5 V is a
  300 mA figure and does not scale to nothing at microamps.
- **Sensor off-state leakage is below the noise floor** — far inside the 10 µA
  allowed, and 20× better than the figure twice recorded before the rig was
  clean.
- **Thresholds 170 / 522**, margins 170 and 60 counts across ±15 % supply.
- A constant **−19 mV** sits at PC4 with sensors disconnected (~4 µA sunk
  board-side). Unexplained; 6 counts; invariant with state.

### The lesson this bench day cost

Three complete measurement sets were taken, fitted, documented and committed
before the fourth revealed all three were of a circuit that did not match the
schematic. **The tell was visible in the first set and missed:** *one active*
to *both active* stepped 50 mV where the topology requires it to roughly
double. A model needing a new free parameter for every measurement is
describing the wrong circuit — check the rig before refitting.

### Group B — 74 checks pass, 0 fail

Driven by [`group_b.py`](group_b.py) against the `encoder` build at unit 40.
Holding registers are read as-found and restored with a single atomic FC16 in a
`finally` block, so the run leaves no state behind; the restore is verified and
reported.

| Row | Traces to | Result |
|---|---|---|
| TP-B01 | FR-S01 | **PASS** — `0x0101`, build `0x01`, firmware 1. |
| TP-B06 | FR-MB01, 08–11 | **PASS** — FC03, FC04, FC06, FC16 all accepted. |
| TP-B07 | FR-MB25 | **PASS** — request data big-endian, CRC little-endian, response data big-endian (verified on 30008, whose two bytes differ; 30007 is `0x0101` and would have proven nothing). |
| TP-B08 | FR-MB19 | **PASS** — 40002 = 65000 and = 50 both exception 03, register unchanged at 1000. **Not clamped.** |
| TP-B09 | FR-MB22 | **PASS** — FC16 with one valid and one invalid value rejected whole, neither register moved. |
| TP-B10 | FR-E06 | **PASS** — 40005/40006 at span 63 rejected with exception 03, both unchanged. |
| TP-B11 | FR-MB05 | **PASS** — FC04 to address 247: silent. |
| TP-B11 | FR-MB06 | **PASS** — broadcast FC06 silent **and not executed**; 40001 unmoved. |
| TP-B12 | FR-MB02, FR-S35 | **PASS** — corrupted CRC: silent, 30009 +1, 30010 +0. |
| TP-B13 | FR-MB13 | **PASS** — input 0x0020: exception 02. |
| TP-B15 | FR-MB03 | **PASS** — both halves; see below. |
| TP-B17 | FR-MB08 | **PASS** — 30001–30015 all readable. |
| TP-B18 | FR-MB09 | **PARTIAL** — 40001–40007 all readable. They equal the §2.8 defaults, but see the caveat below: that does **not** verify them. |
| TP-B25 | FR-MB12 | **PASS** — FC01, FC02, FC05 each exception 01. |
| TP-B26 | FR-MB14 | **PASS** — 12 registers from 0x000A spans the map edge: exception 02, no partial data. |
| TP-B27 | FR-MB15 | **PASS** — FC06 to holding 0x0020: exception 02. |
| TP-B28 | FR-MB30 | **PASS** — FC06 response byte-identical to the request; FC16 response PDU is `00 01 00 02`, address and quantity, not data. |
| TP-B30 | FR-MB18 | **PASS** — only codes 01, 02, 03 observed across the whole group. |
| TP-B31 | FR-MB17 | **PASS** — never silent on a valid addressed request. |
| TP-B16 | FR-S35 | **PASS** — 20 good + 10 corrupted frames: 30010 +20, 30009 +10. Exact, both counters. |
| TP-B14 | FR-MB20 | **PASS** — n=1000, median **4.08 ms**, max **4.14 ms** against a 100 ms limit. See below. |
| TP-B29 | FR-MB21 | **PASS** — **100 %** within 15 ms, where 95 % is required. |
| TP-B05 | FR-S34 | **PASS** — monotonic over 10 min, 605 s counted in 606 s (0.18 %). |
| TP-B02 | FR-S03, FR-MB05, FR-MB07 | **PASS** — bridged: answers at 45, silent at 40. Moved back to open while running: **no effect until reset**. |
| TP-B04 | FR-S32 | **PASS** — 30007 identical across a real power cycle. |
| TP-B19 | FR-S39 | **PASS** — all six persisted holdings survived exactly; 40007 correctly did not. |
| TP-B21 | FR-S20 | **PASS** — watchdog recovered the stalled loop in **1.20 s**, no power cycle (budget 3 s). |
| TP-B22 | FR-S21 | **PASS** — six post-reset state checks; see below. |
| TP-B01b | FR-S01, FR-S32 | **PASS** — `encoder` reports `0x0101`, `encoder_test` reports `0x8101`. The bench image is now identifiable over the bus. |
| TP-B20 | FR-S39 | **ACCEPTED at 13 of 20 cycles**, no corruption. See below. |
| TP-B35 | FR-S16, FR-MB23 | **PASS** — 10 000 cycles, 30009 unchanged, 30010 advanced by exactly 10 000. See below. |
| TP-B24 | FR-S19 | **PASS** (partial scope) — bus never left the fail-safe bias across a real power cycle; peak 0.296 V. See below. |
| TP-B33 | FR-MB28 | **PASS** — FC03/FC04 quantity 0 and 126, FC16 quantity 0 and byte-count mismatch: exception 03 each, nothing modified. |
| TP-B34 | FR-MB24 | **PASS** — a 514-byte burst and a corrupt frame both discarded, and the device still answered the next valid request. |
| TP-B32 | FR-MB04 | **PASS** — DE asserted 3–82 µs before the first start bit, released 3–6 µs after the last stop bit, against a 1 146 µs budget. See below. |

**TP-B18 is PARTIAL, and the reason is easy to miss.** The registers read
exactly the §2.8 defaults — but only because they were *written* back to those
values by hand after an earlier run was killed mid-suite. No factory reset
happened. Finding the defaults present therefore says nothing about what a
factory reset produces, which is what the row actually asks. §7 of the plan
already notes that no factory-reset procedure is defined; until one exists this
row cannot be closed, and the run reports the precondition rather than claiming
a pass it has not earned.

**FR-MB06 is a deliberate deviation and it holds.** Broadcast writes are
ignored rather than executed, against Modbus-over-Serial-Line V1.02 §2.2. The
test plan's original pass criterion said "action without response", which is the
specification's behaviour and not this device's; the row was corrected to match
FR-MB06 before it was run, and both halves — no reply *and* no side effect —
were checked.

**FR-S31 admits only one invalid ordering.** TP-B09 asks for a register pair
that is valid while the intermediate states are not. Since the constraint is
(40003 × 1000) ≥ 40002, making *both* orderings invalid would require 40003 to
be simultaneously larger and smaller than its previous value. The row therefore
exercises the one direction that is genuinely unreachable register-by-register:
40002 = 60000 with 40003 = 60, accepted as a pair, where writing 40002 first
would violate FR-S31.

### Response latency — measured against DE, and a retracted number

**TP-B14 (FR-MB20) and TP-B29 (FR-MB21) — PASS**, n = 1000 at the plan's 50 ms
spacing:

| | |
|---|---|
| Median | **4.08 ms** |
| p95 | 4.13 ms |
| Maximum | **4.14 ms** (FR-MB20 limit: 100 ms) |
| Within 15 ms | **100 %** (FR-MB21 requires 95 %) |
| Unanswered | 0 |
| DE pulse-width error, worst of 1000 | **0.000 ms** |

The spread across 1000 polls is 60 µs, and the figure is physically coherent:
**t3.5 at 9600 is 4.01 ms**, so the DUT waits exactly the frame-boundary silence
Modbus requires and then answers within about 20 µs of it. FR-MB20 measures from
the last request byte, so that mandatory silence is inside the number — the
firmware's own contribution is the 20 µs, and the requirement is met with a
factor of ~24 in hand.

**A previous figure of 11.85 ms is retracted.** It was wrong, not merely
imprecise, and it was wrong for an instructive reason.

FR-MB20 is a wire timing, so it needs the instant our own last stop bit ended.
The first method took that from the RX line — first edge in the capture, plus
the known frame length. That assumes our transmission appears on RO. **It does
not:** R̄Ē is tied to DE on the raw master, so the DUT's receiver is disabled
while we transmit, and the first edge in the capture is RO's enable transient.
Every sample was measured from an origin roughly 70 bit times off.

The measurement now uses **DE**, which we drive ourselves and which is captured
on the same timebase in the same acquisition:

    our last stop bit ends at (DE falling edge) − LEAD_SAMPLES

Nothing is inferred. The **DE pulse width** is the check that the readback is
really our driven line: it must equal `2·LEAD + 10 bit times per byte sent`, and
across all 1000 polls the error was **zero samples**. The reply is then the first
RX falling edge still low half a bit later — a real start bit, which RO's
transient is far too short to imitate.

**What caught it was a cross-check, not a review.** The first version of the
row was recorded as provisional precisely because its derivation rested on one
route; adding a second route made all 1000 samples disagree and the row reported
`1000 suspect` rather than a plausible number. Had it not cross-checked, 11.85 ms
would have gone into this report as evidence and looked entirely reasonable —
comfortably inside both limits, tightly distributed, and wrong.

The row also reported **FAIL** on that run, which was the wrong verdict: an
unmeasurable timing says nothing about whether the device met it. It now reports
**BLOCKED** when the DE readback is unusable, so a limitation of the rig can
never be read as a defect in the DUT.

### One row of mine was measuring the wrong thing

TP-B15's second half originally sent two requests to the DUT's own address 6 ms
apart in a single burst, expecting both to be served. It failed. The DUT was
correct: **response latency is ~11.9 ms**, so it began replying to the first
frame while the master was still transmitting the second. That is bus
contention, and no frame-boundary requirement is under test in it.

Rebuilt so the two halves are isolated: the **first** frame is addressed to unit
247, which FR-MB05 obliges the DUT to ignore, so nothing contends and only
boundary detection is exercised.

- **2.01 ms gap (below t3.5)** → merged into one frame, CRC fails: 30009 +1,
  30010 +0. Correct.
- **6.02 ms gap (above t3.5)** → split into two frames, the 247 one ignored and
  ours served: 30009 +0, 30010 +1. Correct.

Two further failures in the first run were an arithmetic error of mine, not the
DUT: exactly **one** served request falls between two consecutive counter reads,
and the code subtracted that increment twice.

### TP-B21 / TP-B22 — watchdog recovery and the state after it

Flashed `encoder_test` (`Verified OK`), ran the row, reflashed `encoder`
(`Verified OK`) and confirmed the hook was gone before continuing.

**TP-B21 (FR-S20) — PASS.** Writing magic `0xDEAD` to holding `0x00FF` stopped
the main loop refreshing the IWDG. The write itself was answered; the device
then went silent and **answered a valid FC04 again 1.20 s later, with no power
cycle**, against FR-S20's 3 s budget. The 1.20 s includes this script's ~0.15 s
poll granularity, so the true IWDG period is at or under that and inside
FR-S20's 100 ms–2 s window.

The row first proves the device actually *stopped* answering. Without that, a
watchdog that never fired and a device that never hung are indistinguishable,
and the row would pass while testing nothing.

**TP-B22 (FR-S21) — PASS**, six checks after that reset:

| Check | Result |
|---|---|
| Uptime restarted (32 s → **0 s**) — a real reset, not a stall that cleared | PASS |
| Holdings restored to persisted values `[0, 1000, 10, 10000, 0, 1023]` | PASS |
| 40007 (teach) reads 0 — deliberately not persisted | PASS |
| Measurement registers 30001–30005 cleared | PASS |
| Status bit 0 set (first window incomplete) | PASS |
| Status bit 1 set (average not filled) | PASS |
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

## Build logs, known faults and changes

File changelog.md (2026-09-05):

# Changelog

All notable changes to the Wire Encoder Modbus Interface are documented in
this file.

The format is based on [Keep a Changelog](https://keepachangelog.com/), and
this project adheres to [Semantic Versioning](https://semver.org/). No
firmware release has been tagged yet — the version-byte registry lives in
[`software/firmware/RELEASES.md`](software/firmware/RELEASES.md); firmware
version 1 will be tagged `fw-v1` at the first release.

---

## [Unreleased]

### The device

Measures **how far a window is open** — a greenhouse vent, a roof light, a
louvre — and publishes it on Modbus RTU over RS-485. A draw-wire encoder
attached to the moving frame turns a **10 kΩ potentiometer**; the wiper
voltage is an absolute measure of the opening, valid the instant power
returns, with no homing move. Two end-of-travel switches report that the
window has reached a mechanical stop, read as a supervised resistor ladder
that also monitors its own cable.

### Added — project set-up

- Repository bootstrapped from the sibling
  [`windmeters-modbus-interface`](https://github.com/pe1mew/windmeters-modbus-interface)
  project: same MCU (CH32V003J4M6), same RS-485 front-end, same zero-ISR
  architecture, same document structure — and, as it turns out, the same
  potentiometer-on-PA2 sensor topology, which makes that project's vane
  driver the reference implementation for this one's.
- **No wind-sensor content was carried over.** The anemometer and vane
  drivers, the circular-mean and gust machinery, the pulse-counting path and
  the wind-specific HIL scripts are all absent by design. What remains from
  the sibling project is the protocol, platform and bench infrastructure,
  plus factual provenance notes where code was inherited.

### Added — design & requirements

- Design document chain seeded: `design/README.md` (index),
  **`description.md`** (functional description in prose),
  **`requirementsCompliance.md`** (check against the greenhouse-Controller
  M3 requirements study), **`TDS.md` v0.5**, `softwareArchitecture.md`, `driverDevelopment.md`,
  `integrationPlan.md`, `scratchBook.md`.
- **`TDS.md` v0.5 — auto-calibration, and two registers that pay for
  themselves twice.**

  *Auto-calibration from the end switches* (the question asked in
  `scratchBook.md` Q1) is now specified as two cooperating halves rather than
  a single automatic behaviour, because letting a stop silently overwrite a
  calibration point would let one bad reading move every value the device has
  ever reported. **FR-E18** does the observing: whenever the switch loop
  reports a stop, the raw ADC code at that moment is captured and published in
  new input registers 30013 (closed end) and 30014 (open end). It is inert —
  the device reports what it saw and changes nothing. **FR-E19** does the
  committing, and only when told to: writing 1 to new holding register 40007
  sets status bit 5, and the bit clears only when **both** ends have been
  reached *and* both captured values have been read back over the bus. The
  read-back is the interesting part of the handshake — it makes the master's
  own confirmation a precondition, so a teach cannot complete on values nobody
  ever looked at. 40007 is deliberately **not persisted**: a teach in progress
  must not survive a power cut. The commit re-checks the 64-count minimum span,
  because an internal write bypasses the FR-MB19 range check that a Modbus
  write would have hit.

  FR-E18 raises a question the device cannot answer from the loop alone —
  *which* stop was reached, given that the §4.4 ladder resolves "a stop" and
  not "which stop", and that an uncalibrated device cannot infer it from
  position either. The **signed movement rate** settles it. Register 30012
  becomes a **signed int16** (positive = opening, negative = closing), which
  was worth doing on its own — a master can now distinguish a window opening
  from one closing without differencing successive polls — and its sign is
  also what FR-E18 uses to attribute a capture, falling back to proximity only
  when the device was stationary.

  New **FR-E20** adds **percentage of full travel** in input register 30015,
  0.1 % resolution, sharing 30001's 65535 fault sentinel. Trivially derivable
  by the master, but a window is a thing people think about in percentages,
  and putting the conversion here means one definition of "fully open" rather
  than one per client. `scale_percent()` lives in the host-tested `scale.c`
  alongside the opening arithmetic; the host suite is now **38 cases**.

- **`TDS.md` v0.5 — NFR-ENV03 narrowed from IP67 to IP65**, with the selected
  **Kopp 99966478** box named as what sets the figure — the same treatment the
  temperature ceiling got from the LJ18A3 end switch. The principle is that a
  requirement should state what the bill of materials actually delivers, and
  name the part that limits it, rather than assert a number nothing in the
  design meets. IP65 is the greenhouse study's stated *minimum*; its
  preference for IP67 was written for hardware at the aperture, which may be
  rain-wetted with the vent open, and this box holds only the electronics.
  With that settled, `requirementsCompliance.md` §4 was rewritten: both gaps
  it originally raised — potentiometer life and mechanism accuracy — are
  **closed** by the draw-wire supplier specification (>100 000 cycles, 0.2 %
  comprehensive error). Three gaps replace them, two of which arrived with
  the parts chosen since, which is what happens when a compliance analysis
  against a design becomes one against a bill of materials. Only one is a
  requirement *missed* rather than narrowed with its cause named: the
  **draw-wire unit is IP50 and sits outside the enclosure**, so the box that
  now satisfies NF-WP05 protects the electronics and does nothing for the
  sensor hanging on the window frame.
- **`TDS.md` v0.4** — the opening scaling became **direction-agnostic**
  (FR-E04): the two calibration points may be given in either order, so a
  draw-wire mounted such that the wiper code *falls* as the window opens
  calibrates exactly like a normal one, with no invert register and no extra
  installer step. FR-E06 now constrains the *distance* between the points
  rather than their ordering, and adds a **minimum span of 64 counts** —
  applied to values loaded from flash as well as to Modbus writes, so a
  degenerate stored pair can never reach the divisor. The arithmetic moved
  into a hardware-free `scale.c` and is **host-tested at its corners in both
  mounting senses** (`software/firmware/test/test_scale.c`), which is how a
  documented overflow figure was found to be wrong by ~393 000 — the margin
  is 196 605 (0.0046 %), not the threefold-larger value first written down.
  v0.4 also adds **FR-E17, a maximum-age contract**: the value in 30001 is
  never older than the configured measurement window, so a master bounds
  staleness by setting one register rather than by any freshness protocol.
  (Sampling on demand was considered and dropped — unnecessary once the age is
  bounded, and it would have left the averaging, envelope and rate registers
  without the regular cadence they need.)

  And it closes the environmental questions: §4.5 records the IP65 enclosure
  with all connectors inside it, glanded field cables, terminal blocks for the
  sensor and switch loop, and a **pressure-equalisation vent plug** — which
  matters more than it looks, because a fully sealed box uses its own seals as
  a valve every night as it cools, drawing water in. NFR-ENV02…05 make
  condensing operation, ingress, UV and vibration testable. New §4.6 gives the
  reason conformal coating is *specified* rather than merely advisable: the
  wiper is a 2.5 kΩ node, greenhouse condensate is ionic, and surface leakage
  of 100 kΩ costs 1.2 % of full scale — so coating is part of the accuracy
  budget, not a longevity nicety, and a damp uncoated board would fail FR-E03
  silently.
- **`TDS.md` v0.3** — end-of-travel switches became **mandatory** and moved
  from a single digital input to a **supervised resistor ladder on PC4**
  (ADC channel 2, §4.4), with the address jumper moving to PC1. The swap is
  the point: PC4 carries an ADC channel and PC1 does not, so the analog pin
  goes to the thing at the far end of a cable and the boot-time jumper takes
  the digital pin. The ladder resolves five states — cable open, normal, one
  switch closed, both closed, cable shorted — so a cut or shorted switch
  cable is distinguishable from a switch operating. Status register 30006
  gained bit 4 (switch-loop fault) alongside bit 3 (end of travel reached);
  bit 2 was renamed *wiper* fault, since there are now two independent
  front-ends that fault separately (FR-E14/E15/E16). The `HAVE_END_SWITCH`
  build option and the `encoder_endswitch` environment are gone with it.
  Derivation, including why the ladder cannot resolve *which* switch and
  supervise the cable at the same time, is in `design/scratchBook.md`.
- **`TDS.md` v0.2** — §2 (Modbus RTU contract, FR-MB01…FR-MB30) carried over
  unchanged from the windmeters TDS v0.9, where every row is HIL-verified
  against the same driver binary. §2.7/§2.8 replaced with the window-opening
  register map: 12 input registers (opening instantaneous / averaged /
  window min / window max, raw ADC code, status, identification, uptime, CRC
  and served counters, seconds-since-valid-reading, movement rate) and 6
  persisted holding registers (zero offset, measurement window, averaging
  window, full travel, two-point raw calibration). §3 keeps the proven
  lifecycle requirements (FR-S01…FR-S03, FR-S18…FR-S24, FR-S30…FR-S36,
  FR-S39) and adds a new **FR-E** series for the measurement path. §4
  hardware is open.
- **§4.2 documents the real pin budget.** The J4M6 SOP-8 bonds several GPIO
  onto shared pins (pin 1 is PD6 *and* PA1; pin 8 is PD1, PD4 *and* PD5), so
  there are six physical I/O pins, not the seven a port-name list implies.
  **Every one is now committed**; any front-end idea needing another pin
  does not fit.
- UML: `design/diagrams/modbus_state.puml` carried over (protocol behaviour
  is unchanged, title retargeted); component and super-loop diagrams redrawn
  for the encoder module split.

### Added — software (carried over, HIL-verified in the source project)

- `software/drivers/modbus_rtu/` — Modbus RTU slave driver (`mb.c`/`mb.h`):
  framing/CRC, t3.5 gap detection, address filtering, FC03/04/06/16,
  standard exceptions, no-clamp range rejection, atomic FC16,
  remap-switching line discipline (no HDSEL), polled RX (zero ISRs). Its
  test shell was retargeted to this project's register map and address.
- `software/drivers/common/debug_uart/` — bench trace UART.
- `software/drivers/blinky_template/` — bare-MCU bring-up project.
- `software/firmware/src/board.{c,h}` — RS-485 quiescing, jumper address
  latch, IWDG and PVD (FR-S18/S20/S22), with the address retargeted to
  40/45 and the jumper moved to PC1.
- `software/firmware/src/persist.{c,h}` — power-loss-safe ping-pong flash
  store for the six holding registers (FR-S39), fields retargeted to this
  holding set and the store magic changed to `'WE'` so a windmeters record
  left in a re-flashed chip can never be read as valid.
- `software/hil/` — Saleae/M2K instrument scaffolding and the acceptance
  suite shell, plus the bench-quirk catalogue in its README — the hard-won
  part.

### Added — software (new)

- `software/firmware/` — product-firmware skeleton. **One release build**
  (`encoder`, build byte 0x01, address 40/45), with `encoder_test`
  (bench-only) beside it. `regs.{c,h}` implements the full §2.7/§2.8
  register image with the FR-S31 + FR-E06 cross-validate hook, the §4.4
  ladder band decode and the FR-E15 debounce. Measurement registers read
  their FR-S23 pre-first-window value until the encoder driver lands.
  The FR-E04 scaling lives in a hardware-free `scale.{c,h}` with a host test
  in `software/firmware/test/`. As-built: 3 604 B flash / 616 B RAM
  (25 % / 34 % of the NFR-RES01 ceilings).
- `software/drivers/wire_encoder/` — driver-project shell with the drafted
  `we.h` API contract; **no implementation yet**, deliberately, so the
  firmware cannot link against a stub that looks like a driver.

### Added — software, integration stages D–F (2026-09-01)

The firmware went from skeleton to complete. All of the below is HIL-verified;
evidence in [`software/hil/testReport.md`](software/hil/testReport.md).

- **`we.c` — the ADC driver** (stage D). 16-conversion ratiometric burst on the
  wiper (PA2/ch0), the switch ladder on PC4/ch2, FR-E07 float detection by
  pull-resistor toggle. ADC at 12 MHz (`RCC_ADCPRE_DIV4`), sample time
  **241 cycles**.
- **`meas_open.c` — the measurement service** (stage D). Paced at 40 Hz, with
  the wiper and the switch ladder on **alternate ticks**.
- **`avg.c` — FR-S31 averaging** (stage E). One 64-entry ring of
  (mean, min, max), ~384 B; exact for windows ≤64, blocks of ⌈N/64⌉ above.
  Blocks carry **min/max, not a block mean**. 26 host tests.
- **`health.c` — FR-E23 and FR-E24 sensing health** (stage F). Status **bit 7**
  reports a position that does not follow the carriage — the draw-wire snapped,
  tangled or slipping, which is electrically invisible. Status **bit 6** reports
  a raw code outside the plausible band. FR-E24 is **self-disabling** on a
  full-range calibration, which is what lets it need no persisted "was taught"
  flag and leaves `rec_t` at 20 bytes. 25 host tests.
- **Traceability gates** — `software/hil/acceptance/test_traceability.py` fails
  the build if any TDS requirement has no test row, if a row cites an id that
  does not exist, or if an id is abbreviated (`FR-E01, E02` hides two ids from
  every checker). Covers all four requirement families.
- As-built: **6 364 B flash (44.4 %) / 1 108 B RAM (61.8 %)**.

### Fixed (2026-09-01)

- **FR-E12 violated by the ADC driver.** `we.c` configured a 73-cycle sample
  time. FR-E12 requires **≥241**: FR-E21's 10 kΩ series protection lifts the
  source impedance to 12.5 kΩ, above the 10 kΩ the old ≥71 figure was chosen
  for. The driver had been written to `we.h`'s front-end note, a *copy* of the
  requirement that had already drifted. Corrected in the driver, and on
  2026-09-05 in the five documents that still quoted the superseded number —
  including the TDS itself, twice.
- **Requests silently lost when a loop pass ran long.** `mb_rx_service` polls a
  single-byte USART register, so a pass longer than one character time
  (**1.146 ms** at 9600) loses a byte to overrun; FR-MB24 then discards the
  frame *without* incrementing 30009, because an overrun is not a CRC error.
  Stage D dropped 9.7 % of requests before this was found. Fixed by splitting
  the wiper and ladder across alternate ticks. **This budget appears in no
  requirement** — it is documented in the firmware README and §5 of
  `softwareArchitecture.md`.

### Changed — requirements (2026-09-01)

- **TDS to v0.7.** FR-E23 and FR-E24 added; FR-S33 and §2.7 define status bits
  6 and 7; **FR-E07 narrowed to opens only** — a wiper shorted to either rail is
  indistinguishable from a legitimate end-stop reading, so claiming to detect it
  was false; FR-MB07 added to NFR-TST01's exception list; FR-MB28's ">123"
  clause dropped.
- **FR-E22 deliberately not adopted.** It false-alarms in the real geometry,
  where clamping is the resting state, and the latch that would fix it blinds it
  to the frozen wiper it was invented for. The numbering skips E22 so the
  adopted ids stay stable. Reasoning in `design/scratchBook.md` Q4.
- **FR-WP07 flagged conditional.** Status bit 3 reports the *sensor*, not the
  window: where a sensor's active zone is narrow and the leaf travels past it,
  bit 3 reads *not at a stop* with the window fully closed.
- **Installation requirements** (`design/description.md` §8.1). The draw-wire
  must have **≥10 % headroom at each end** of travel and must never be linked to
  the window's physical end positions. This is load-bearing, not advice: if
  fully-closed sits at an electrical extreme, a shorted conductor reads exactly
  like a correctly closed window and no firmware can separate them.

### Added — client interface contract (2026-09-05)

- **`docs/modbusInterfaceContractSpecification.md`** — the greenhouse
  controller's contract with this device, organised by purpose: polling for the
  opening, end switches, teaching, alarms versus health. Every statement cites
  the TDS requirement it derives from; worked frames carry CRCs computed with
  the project's codec. Two facts in it come from the implementation rather than
  the TDS: the teach commit waits for the controller to **read** both captured
  endpoints, so the ordinary full-map FC04 poll completes a teach with no extra
  traffic; and a capture is filed to the closed or open register by **direction
  of travel**, so a teach must be done with movement.
- **§8 sized to the target window: 1.5 m in 171 s (the M3 travel time) =
  8.77 mm/s.** *(First drafted from "≈2 minutes" = 12.5 mm/s; corrected the
  same day — the exact figure moves every derived number by ~30 %.)* At that
  speed a 100 ms measurement window moves the leaf less than one ADC count per
  update and quantises the rate register into steps larger than the speed it
  measures; **40002 = 500 for a 1 Hz poll** (FR-WP08 needs the window shorter
  than the poll period, or consecutive polls can repeat a value), 1000 for
  slower polling, with the arithmetic shown.
  **Finding:** the compliance study's FR-WP20 jump-rejection threshold of
  0.58 %/s *is* this window's normal speed (0.585 %/s) — evidently derived from
  the 171 s travel time — so as a limit it has zero margin and would reject a
  healthy reading with one quantisation step on it. The contract sets the
  controller's limit at |30012| > 175, twice nominal. The study's 2 m stroke and 40004 = 20000 are likewise superseded by
  the actual 1.5 m window; `requirementsCompliance.md` still carries the
  study's figures and is not edited, since it records the study as received.

### Hardware decisions

- **End switches: LJ18A3-8-Z/BX inductive proximity sensors** (2026-07-29).
  NPN normally-open, 6–30 V, 8 mm range against a 30 × 30 × 1 mm iron target,
  M18×1, unshielded, with an actuation LED. The supply range spans the board's
  own 24 V PoE rail, so they run off it directly — no extra regulator and no
  load on the 3.3 V. Being non-contact, they retire the 25 000-cycle wear
  concern for the switches; only the potentiometer still carries it.
  Datasheet in `documentation/Proximity-Switch-LJ18A3-8-Z-BX.pdf`. Confirmed
  specs: <13 mA each, <300 mA output, ≈0.8 mm hysteresis, 500 Hz, reverse-
  connection/surge/short-circuit protection, 1.1 m flying lead.
- **§4.4 end-switch interface redesigned as an attenuating divider.** The
  sensors are not open-collector — each has an internal 10 kΩ pull-up to +V
  (`LJ_en.pdf` p. 2), so an inactive one *sources* 24 V rather than floating.
  The previous pull-up-to-3.3 V topology would have sat at **10.4 V with one
  sensor inactive and 14.0 V with both**, against an ADC pin whose maximum is
  a diode drop above 3.3 V — a destroy-the-part error, caught before any board
  existed. The sensor already provides a clean 0 ↔ 24 V signal, so the board
  now **attenuates and clamps** instead of exciting: 100 k per output and a
  470 k end-of-line summed in the field junction, 10 k + 4k7 and a clamp at
  the board. Bands invert — healthy is now the highest reading (547) and a
  dead cable is zero. Three things improved in the process:
  **fail-safe by construction** (the board-side pull-down holds a
  disconnected input at 0, which is the fault band, so nothing reads healthy
  by accident); **saturation voltage almost stops mattering** (the 100 k
  summing resistors reduce its effect from 296 counts to 17, so the unknown
  `Vsat` is no longer make-or-break); and **±15 % supply tolerance is
  absorbed** with ≥45 counts to spare at the tightest point. Given up: the
  measurement is no longer ratiometric, and both-active vs cable-fault are
  only just distinguishable — both are bit-4 faults, so treat them as one.
  `regs.c`'s classifier and thresholds updated to match.
- **The §4.4 bands are measured, not computed** (2026-08-31). All three
  states read on the bench against real sensors, and the fitted model agrees
  to **≤0.1 mV**:

  | State | Measured | Counts |
  |---|---|---|
  | Neither active | 0.329 V | 102 |
  | One active | 1.502 V | 466 |
  | Both active | 2.320 V | 720 |

  Two unknowns resolved, in opposite directions. **The output drop is zero**
  at this network's 290 µA — `Von` = 24.04 V against a 24.04 V supply — so the
  datasheet's ≤2.5 V, a 300 mA figure, does not apply. That closes the §6
  blocker, and it is confirmed twice independently: once from *one active*
  after correcting for leakage, once from *both active*, which carries no
  leakage term at all and still lands on 24.04 V.

  **But the off-state leakage is 35 µA per sensor, 3.5× the specified 10 µA.**
  It lifts the *neither active* floor from a predicted 29 counts to 102 and
  adds 42 to *one active*. Against the computed `SW_TH_BOTH` of 510 that is
  fatal — at +15 % supply *one active* reaches 536 and would decode as a false
  **both active** fault on a healthy installation. Thresholds moved to **256
  and 574**, leaving 139/140 and 38/38 counts either side.

  **What is still open now decides more than the thresholds do.** The 35 µA
  fits two models identically at room temperature: an internal bleeder of
  ≈590 kΩ, which is stable, or junction leakage, which doubles roughly every
  10 °C. Under the second the floor crosses `SW_TH_ONE` after about **12 °C**
  of warming, and the device reports stops that are not there at an ambient
  well inside NFR-ENV01's +70 °C. One warm sensor and a voltmeter settles it.

- **Corrected a proof that had gone stale under the sensor change.**
  `scratchBook.md` argued that a two-switch ladder can resolve *which* switch
  **or** *both closed* but not both, as a property of the topology. That was
  derived for the NPN arrangement and is **not true of the PNP one** — with
  the output sourcing through its summing resistor, asymmetric values can
  separate four states, and scanning E24 against the measured bands finds 202
  workable pairs at ±15 % supply. The conclusion survives, the reasoning does
  not: the best of them (75 k/110 k) leaves **7 counts** at its tightest point
  where the symmetric pair leaves **38**, and 1 % resistors alone consume 6 of
  the 7. The sound argument is that the position registers already resolve
  which end across most of the ADC range, which is how FR-E18 attributes a
  capture — so the switch path spends its resolution on the one thing position
  cannot report. Recorded because a margin argument that has quietly become an
  impossibility claim is exactly what to re-derive after a part change; this
  one nearly went unexamined.

- **End switch changed to the 3RG4023-3AB00, and it inverts the whole
  interface** (2026-08-29, `documentation/6561.pdf`). The LJ18A3-8-Z/BX was
  **NPN** with an internal 10 kΩ pull-up, so an inactive sensor sat *high*.
  This one is **PNP**: inactive is *open*, operated drives *high*. Every level
  in §4.4 inverts, and so do the firmware thresholds — **normal is now the
  lowest reading and a fault the highest.**

  Circuit: **R10 (470 k pull-up) is deleted** — it held *both active* off the
  floor when the NPN outputs pulled down, and against a PNP source it only
  injects an offset into a network that now needs a pull-down. The existing
  10 k + 4k7 attenuator *is* that pull-down, so no part replaces it. **R8/R9
  100 k → 68 k**, sized so *both active* does not clip at +15 % supply while
  keeping the 10 µA off-state leakage clear of the *one active* band. Bands at
  24 V: **29 / 423 / 719 counts**, thresholds 230 and 510.

  **The fault band is gone, and that is inherent rather than an oversight.** A
  PNP normally-open output sources nothing when inactive, when its cable is
  open, and when its signal is shorted to 0 V — all three read ~0 counts.
  Status bit 4 and FR-E16 now cover *both active* and nothing else. Note this
  inverts the *direction* of the undetected failure rather than removing it:
  under the NPN part an open cable read 337 counts and reported a **false**
  stop; now it reads ~0 and reports a **missed** one. `regs.c` loses
  `SW_CABLE_FAULT` entirely and classifies three states, not four.

  **What it buys is bigger than what it costs.** The LJ18A3's +65 °C ceiling
  was NFR-ENV01's limit and **the one requirement this design knowingly failed**
  against the greenhouse study — NF-WP03 asks +70 °C. At **−25…+85 °C** the new
  sensor stops being the constraint, NFR-ENV01 goes to **+70 °C**, and NF-WP03
  moves into the met column. The old §6 entry predicted the fix would be "a
  wider-range end switch"; it arrived as a change of part rather than as a
  survey. Also gained: reverse-voltage, wire-breakage, inductive-overvoltage,
  short-circuit and overload protection all built in, switch-on pulse
  suppression, and an **M12 connector** in place of a 1.1 m flying lead — which
  turns the field joint from a workmanship item into a cordset.

  Two things to watch, both now in §6. The **≤2.5 V output drop is specified at
  the rated 300 mA** and this network draws **290 µA**; the real drop should be
  a fraction of a volt, but nothing guarantees it, and the difference is 23
  counts of margin against 63 — so measuring `Von` at the divider's actual load
  replaces the LJ18A3 bench item as the blocker. And **hysteresis is as low as
  0.04 mm**, twenty times tighter than before, which makes FR-E15's 20 ms
  debounce load-bearing rather than precautionary.

- **D3 selected: PESD5V0S1BA**, 5 V standoff, bidirectional, SOD-323. The
  standoff is deliberately *not* 3.3 V: the wiper swings to 3.3 V, so a
  3.3 V-standoff part would sit at 100 % of its rated working voltage at full
  scale, where leakage is largest and most temperature-dependent. Every
  component on the schematic now carries a footprint. What remains is evidence
  — datasheets quote reverse current at `V_RWM` and 25 °C, which says little
  about 3.3 V at +70 °C, so FR-E21's fit/unfit measurement still has to be made.

- **The wiper had no protection at all, and now does** (2026-08-07,
  FR-E21). PA2 ran bare from the terminal block to the MCU — no series
  element, no clamp — while the switch input two pins away had a 10 k series,
  a divider and a zener. The asymmetry was inherited from the sibling board,
  whose `ANALOG_IN` also went straight from the RJ14 to the pin, and it had
  been sitting in §6 as "wiper ESD protection" since the first draft.

  Fitted: **R11 10 kΩ** in series, **C6 1 nF** as a reservoir and **D3**, a
  TVS. Three things about that set are not the obvious choices.

  **The resistor is the current limiter, not the TVS.** A TVS is a transient
  device and cannot hold a low-impedance 24 V short; a miswired terminal is
  not a transient. 10 kΩ holds a 27.6 V fault (24 V passive PoE at +15 %) to
  **2.4 mA** against the CH32V003's **±4 mA** injected-pin absolute maximum —
  the same ≈2 mA design point §4.4.2 had already chosen for the switch input.

  **The capacitor is what makes a 10 kΩ series resistor affordable.** The
  ADC's sample capacitor charges from the reservoir instead of through the
  resistor, which only has to recharge 1 nF between conversions: 12.5 µs
  against a ≥100 ms window. It is deliberately *small* — FR-E07 detects an
  open wiper by toggling the internal pull resistor between conversions, and
  at tens of kΩ that pull settles through 1 nF in ~40 µs where 100 nF would
  take 4 ms and start eating the measurement cadence. FR-E12's sample time
  goes to ≥241 cycles anyway, which costs ~42 µs per conversion and removes
  any need to lean on the reservoir argument.

  **The clamp is a specification, not a preference** (new §4.6.1). §4.6's
  ≥10 MΩ wiper-node rule has always been read as being about moisture; it is
  really about any current path off that node, which makes it a component
  rule too. It disqualifies both obvious candidates: the **BZX84-C3V3**
  already used on PC4 leaks microamps well below breakdown and *non-linearly*,
  ≈12 mV or 4 counts that calibration cannot remove; and **BAT54S**, the
  reflex ADC clamp, leaks ~2 µA at 25 °C and roughly doubles per 10 °C, so at
  NFR-ENV01's +65 °C ceiling it is ≈32 µA — **80 mV, 25 counts, 2.4 % of full
  scale** against a sensor specified at 0.2 %. The trap is that PC4 and PA2
  sit at comparable impedance so the PC4 clamp looks transferable; the
  difference is not impedance but that PC4 resolves four bands with 45 counts
  of margin while PA2 is the measurement the product exists to make. D3 is
  therefore specified at **≤100 nA at 3.3 V across the full NFR-ENV01 range**
  and left with a blank footprint so it cannot be laid out unselected.

- **The installation is a star, and it costs the cable supervision**
  (2026-08-07). The PCB is the hub; the draw-wire and **each** end switch run
  their own cable to it. There is no field junction, so the 100 k summing
  resistors and the 470 k have nowhere to live except the PCB — and an
  end-of-line resistor at the near end of the line is not an end-of-line
  resistor. The four band levels are unchanged; what changed is what a fault
  looks like. An open sensor cable removes that branch's pull-up, and
  *removed* lands between *inactive* and *active*: **337 counts, 38 from a
  genuine stop at 299, inside the same band**. So a cut does not report a
  fault, it reports **a stop that did not happen** — worse than a detected
  fault, because the controller acts on it instead of alarming. It cannot be
  tuned out: the bands need 45 counts of margin for supply tolerance alone,
  and a fifth state does not fit between four on one 10-bit pin. FR-E16 and
  status bit 4 are narrowed to cover a short to 0 V and both-switches-active
  only; FR-E14's verification gains a negative test that confirms the limit
  rather than contradicting it. The 470 k stays on the board with a new job —
  it is what holds *both active* at 56 counts instead of collapsing it onto
  *shorted* at 0.

  The trade is not one-way. Field-mounted 100 k and 470 k would have sat
  uncoated in the dampest part of the installation, where §4.6's own figures
  say contaminated films reach 100 kΩ–10 MΩ without difficulty — and against
  this network a **182 kΩ** leak from signal to +V *masks a real stop*, five
  times easier to reach than the 37 kΩ that would invent a false one, sitting
  between two adjacent terminals, failing in the direction where the window
  keeps driving. On the PCB, inside IP65 and coated, neither number matters.
  The star moves one hidden failure out of the harness and turns one
  detectable failure into a hidden one. A firmware mitigation is available
  and deliberately not yet specified: after FR-E19 has taught the endpoints, a
  stop claimed while the wiper sits far from either calibrated end is
  implausible, and the two independent front-ends can cross-check. Recorded in
  TDS §6 with the two questions it still needs answered.

  Knock-on: the enclosure now uses **all six** entries — bus in, bus out,
  draw-wire, switch A, switch B, vent — with none spare.

- **⛔ Superseded — the original open-collector assumption.**
  The manufacturer's manual (`LJ_en.pdf` p. 2) shows the NPN output carries an
  **internal 10 kΩ pull-up to +V** — it is not a bare open collector and does
  not float when inactive. The §4.4 network, which assumes it floats and pulls
  it up to 3.3 V, would sit at **10.4 V with one sensor inactive and 14.0 V
  with both**, against an ADC pin whose maximum is a diode drop above 3.3 V.
  That is a destroy-the-part error, not a calibration one. The interface has to
  become an attenuating divider referenced to the sensor supply; the
  supervision concept survives, the topology and values do not. Verify on the
  bench first: brown-to-black with the sensor unpowered should read ~10 kΩ.
- **⚠ /BX is NPN; /BY is PNP — and one of the supplied datasheets is the /BY.**
  The board pulls PC4 up to 3.3 V and relies on the sensor *sinking* it, which
  is safe only for an open-collector output. A PNP part sources its own supply
  rail and would put 24 V on an ADC pin. Check the marking on the sensor, not
  the paperwork that came with it.
- **NFR-ENV01 narrowed to −25…+65 °C**, and it now names what sets the limit:
  the LJ18A3-8-Z/BX end switch (−30…+65 °C) is the narrowest part in the chain;
  the electronics would have carried +70 °C. Stating the real figure beats
  leaving a requirement the BOM cannot meet. The acceptance criterion also
  gained a row — the §4.4 switch bands must decode correctly at both extremes,
  because an NPN saturation voltage drifts with temperature. Consequence: this
  is 5 °C below the greenhouse study's NF-WP03, and is now the one requirement
  the design knowingly does not meet in full; the resolution is a survey of the
  mounting position and, if needed, a wider-range switch.
- **⚠ The §4.4 ladder band values are now provisional.** They were derived for
  dry contacts closing to 0 Ω. An NPN output closes to its saturation voltage
  instead, which shifts every active band upward — enough that at 0.5 V a
  wiring fault decodes as a normal end-stop, and at 1.5 V an actively
  signalling sensor decodes as *no sensor active*. Both are silent
  mis-decodes. `Vsat` is not stated in either supplied document and must be
  measured, then the resistors and thresholds re-derived, before the schematic
  is committed (TDS §6). Recommended at the same time: merge "both active" and
  "cable shorted" into one fault band — they are both impossible states, both
  set the same status bit, and merging them recovers most of the lost margin.
- **New failure mode to design out:** with powered sensors, a break in the +V
  conductor alone kills both while the EOL resistor keeps the loop reading
  healthy. Dry contacts did not have this. Fixable by deriving part of the
  pull-up from the sensors' +V at the far end.

### Notes

- `documentation/` contains a Mann Hwa / Zhongyang ZY-series encoder
  catalogue PDF. It describes **incremental** rotary encoders and **does not
  describe the sensor this project uses** — see `documentation/readme.md`.
  Do not design against it.

---

*Nothing released yet.*

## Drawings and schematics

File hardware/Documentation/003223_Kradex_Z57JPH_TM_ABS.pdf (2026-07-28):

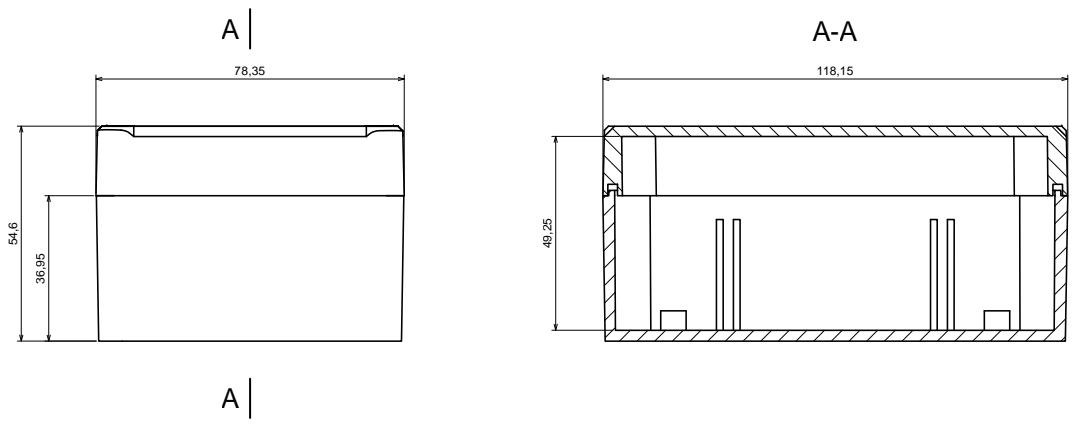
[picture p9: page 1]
Product model Format: A3 Scale 1:1; Tolerance: +/- 0.5 Material: PS, ABS Enclosure Z57 - assembly All rights reserved, Copyright Kradex 2016

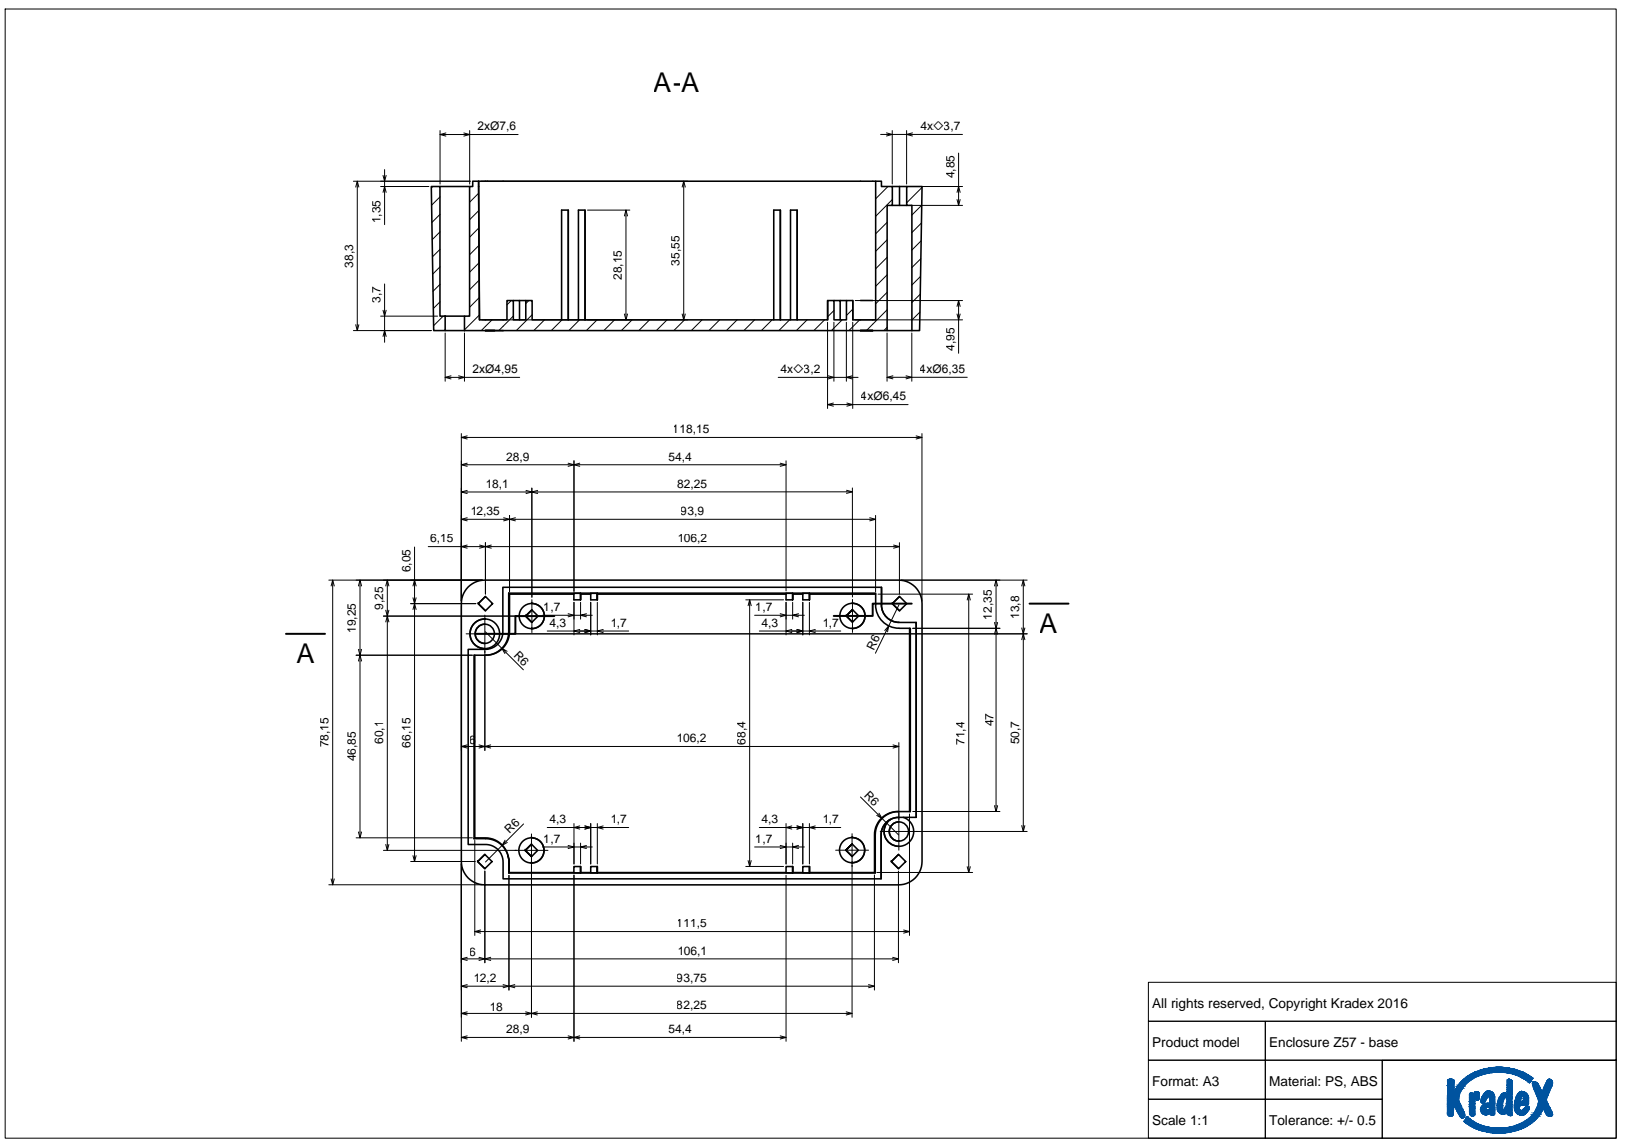
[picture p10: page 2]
Product model Format: A3 Scale 1:1; Tolerance: +/- 0.5 Material: PS, ABS Enclosure Z57 - base All rights reserved, Copyright Kradex 2016 1,74,3

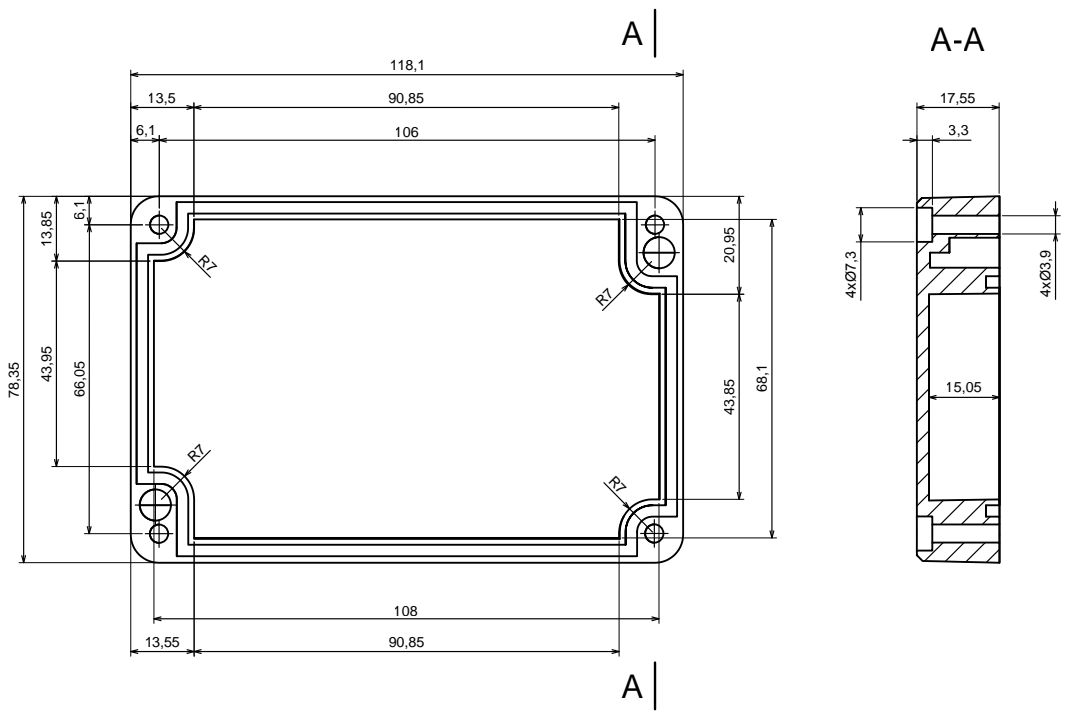
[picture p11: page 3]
Product model Format: A3 Scale 1:1; Tolerance: +/- 0.5 Material: PS, ABS Enclosure Z57 - cover All rights reserved, Copyright Kradex 2016 6,1

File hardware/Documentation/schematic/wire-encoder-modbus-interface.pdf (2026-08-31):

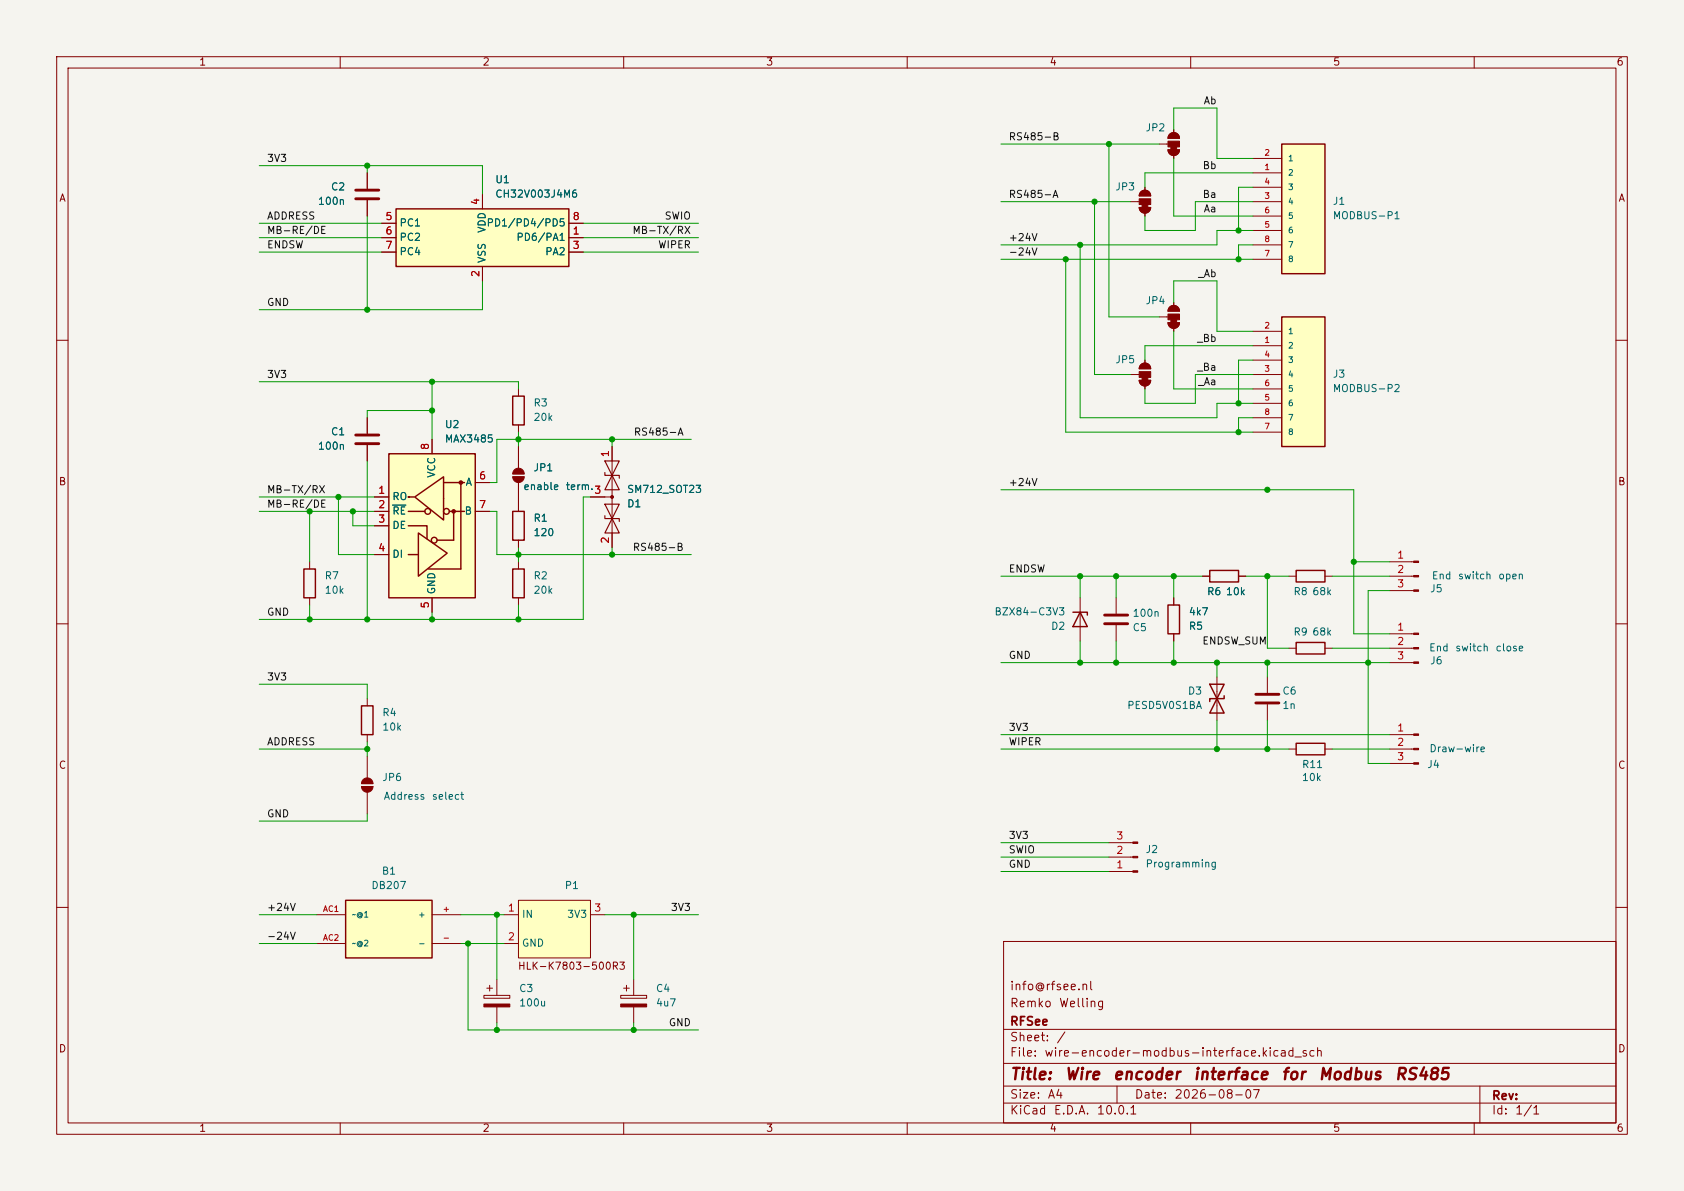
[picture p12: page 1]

ADDRESS
MB-TX/RX GND

GND MB-RE/DE

Remko Welling
RFSee
Sheet: /
File: wire-encoder-modbus-interface.kicad_sch
Title: Wire encoder interface for Modbus RS485

Size: A4 | Rev:
KiCad E.D.A. 10.0.1 | Id: 1/1

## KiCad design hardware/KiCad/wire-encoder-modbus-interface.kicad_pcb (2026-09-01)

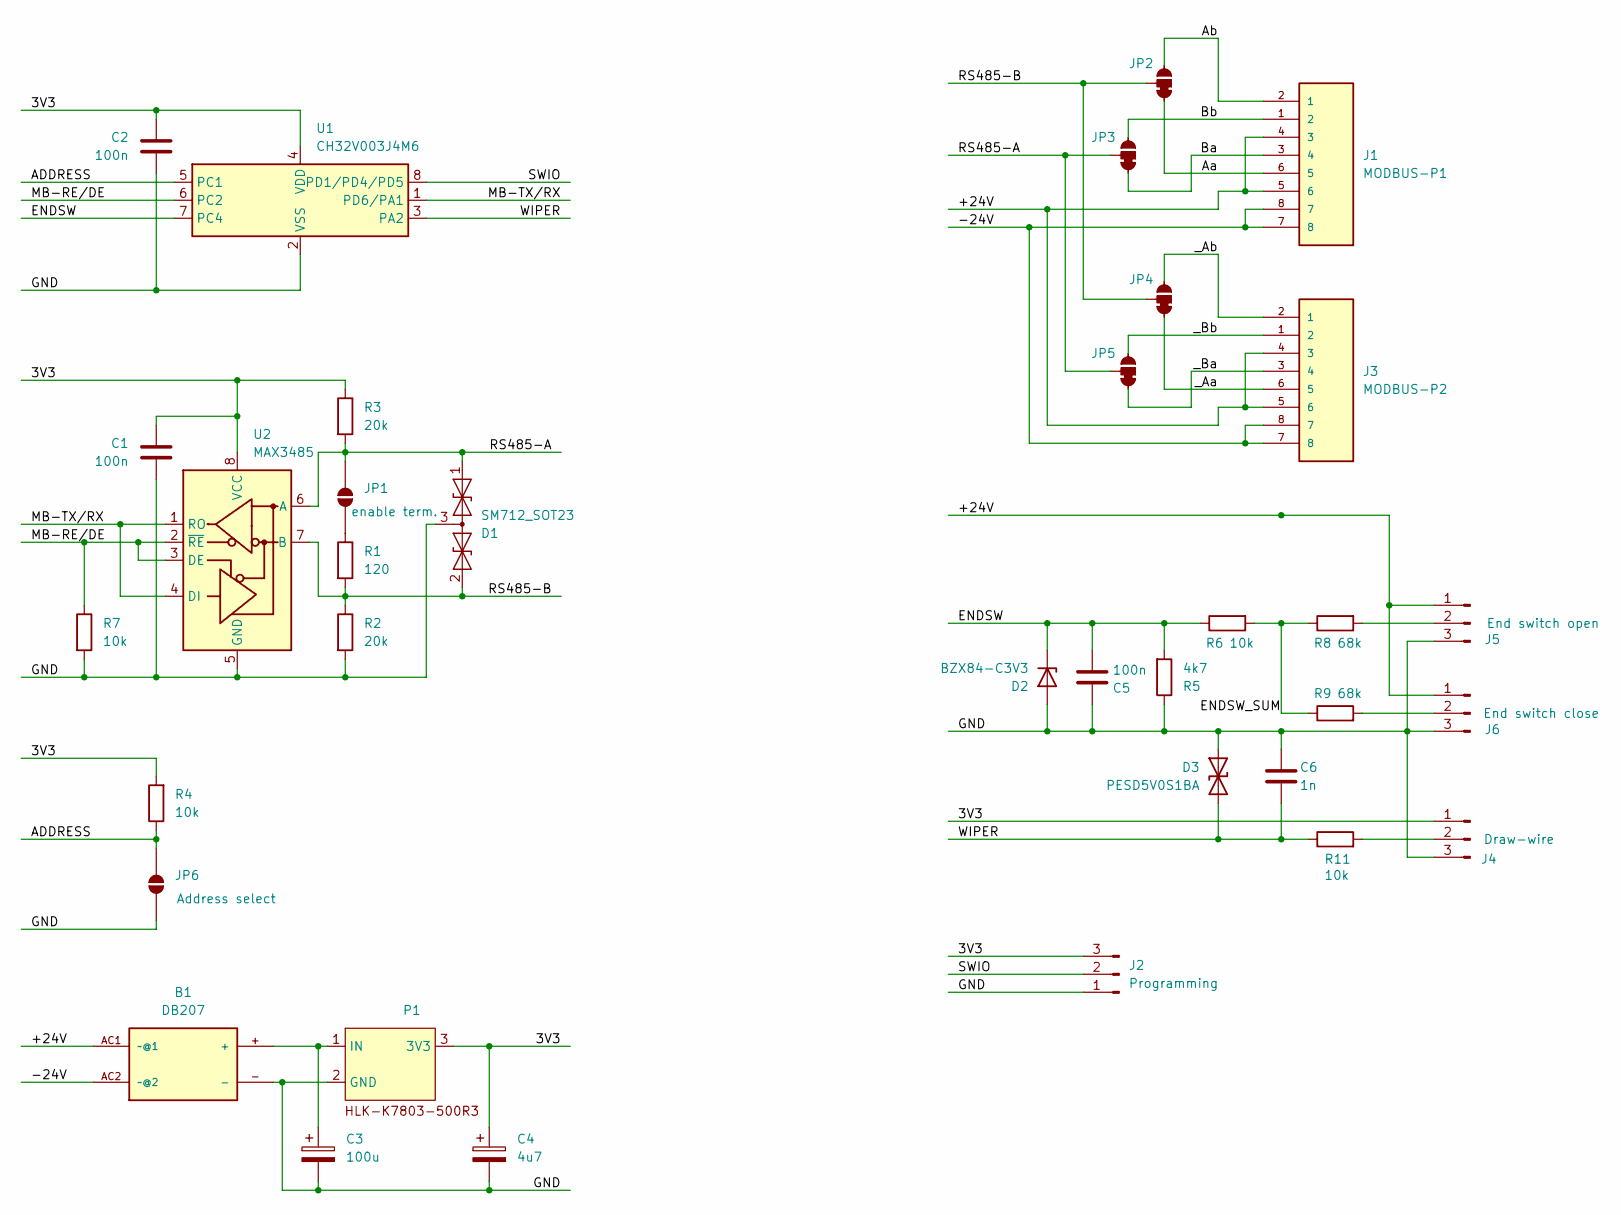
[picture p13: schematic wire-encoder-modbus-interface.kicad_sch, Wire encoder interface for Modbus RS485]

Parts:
B1: DB207; DB207-DIP-4
C1, C2, C5: 100n; C_1206_3216Metric_Pad1.33x1.80mm_HandSolder
C3: 100u; CP_Radial_D8.0mm_P5.00mm
C4: 4u7; CP_Radial_D5.0mm_P2.50mm
C6: 1n; C_1206_3216Metric_Pad1.33x1.80mm_HandSolder
D1: SM712_SOT23; SOT-23
D2: BZX84-C3V3; SOT-23
D3: PESD5V0S1BA; D_SOD-323_HandSoldering
J1: MODBUS-P1; CONN_215877-1; PARTREV AF1
J2: Programming; PinHeader_1x03_P2.54mm_Vertical
J3: MODBUS-P2; CONN_215877-1; PARTREV AF1
J4: Draw-wire; JST_NV_B03P-NV_1x03_P5.00mm_Vertical
J5: End switch open; JST_NV_B03P-NV_1x03_P5.00mm_Vertical
J6: End switch close; JST_NV_B03P-NV_1x03_P5.00mm_Vertical
JP1: enable term.; SolderJumper-2_P1.3mm_Open_Pad1.0x1.5mm
JP2, JP3, JP4, JP5: SolderJumper-3_P1.3mm_Bridged12_Pad1.0x1.5mm_NumberLabels
JP6: Address select; SolderJumper-2_P1.3mm_Open_Pad1.0x1.5mm
P1: HLK-K7803-500R3
R1: 120; R_1206_3216Metric_Pad1.30x1.75mm_HandSolder
R2, R3: 20k; R_1206_3216Metric_Pad1.30x1.75mm_HandSolder
R4, R6, R7, R11: 10k; R_1206_3216Metric_Pad1.30x1.75mm_HandSolder
R5: 4k7; R_1206_3216Metric_Pad1.30x1.75mm_HandSolder
R8, R9: 68k; R_1206_3216Metric_Pad1.30x1.75mm_HandSolder
U1: CH32V003J4M6; JEITA_SOIC-8_3.9x4.9mm_P1.27mm
U2: MAX3485; SOIC-8_3.9x4.9mm_P1.27mm

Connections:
/3V3: C1.1, C2.1, C4.1, J2.3, J4.1, P1.3 (3V3), R3.1, R4.2, U1.4 (VDD), U2.8 (VCC)
/+24V: B1.AC1 (~@1), J1.4 (3), J1.5 (6), J3.4 (3), J3.5 (6), J5.1, J6.1
/-24V: B1.AC2 (~@2), J1.7 (8), J1.8 (7), J3.7 (8), J3.8 (7)
/ADDRESS: JP6.2 (B), R4.1, U1.5 (PC1)
/Aa: J1.6 (5), JP2.1 (A)
/Ab: J1.2 (1), JP2.3 (C)
/Ba: J1.3 (4), JP3.1 (A)
/Bb: J1.1 (2), JP3.3 (C)
/ENDSW: C5.2, D2.3 (K), R5.2, R6.1, U1.7 (PC4)
/ENDSW_SUM: R6.2, R8.1, R9.1
/GND: B1.-, C1.2, C2.2, C3.2, C4.2, C5.1, C6.1, D1.3 (common), D2.1 (A), D3.1 (A1), J2.1, J4.3, J5.3, J6.3, JP6.1 (A), P1.2 (GND), R2.2, R5.1, R7.2, U1.2 (VSS), U2.5 (GND)
/MB-RE/DE: R7.1, U1.6 (PC2), U2.2 (~RE), U2.3 (DE)
/MB-TX/RX: U1.1 (PD6/PA1), U2.1 (RO), U2.4 (DI)
/RS485-A: D1.1 (A1), JP1.2 (B), JP3.2 (B), JP5.2 (B), R3.2, U2.6 (A)
/RS485-B: D1.2 (A2), JP2.2 (B), JP4.2 (B), R1.2, R2.1, U2.7 (B)
/SWIO: J2.2, U1.8 (PD1/PD4/PD5)
/WIPER: C6.2, D3.2 (A2), R11.1, U1.3 (PA2)
/_Aa: J3.6 (5), JP4.1 (A)
/_Ab: J3.2 (1), JP4.3 (C)
/_Ba: J3.3 (4), JP5.1 (A)
/_Bb: J3.1 (2), JP5.3 (C)
unnamed: J4.2, R11.2
unnamed: J5.2, R8.2
unnamed: J6.2, R9.2
unnamed: JP1.1 (A), R1.1
unnamed: B1.+, C3.1, P1.1 (IN)

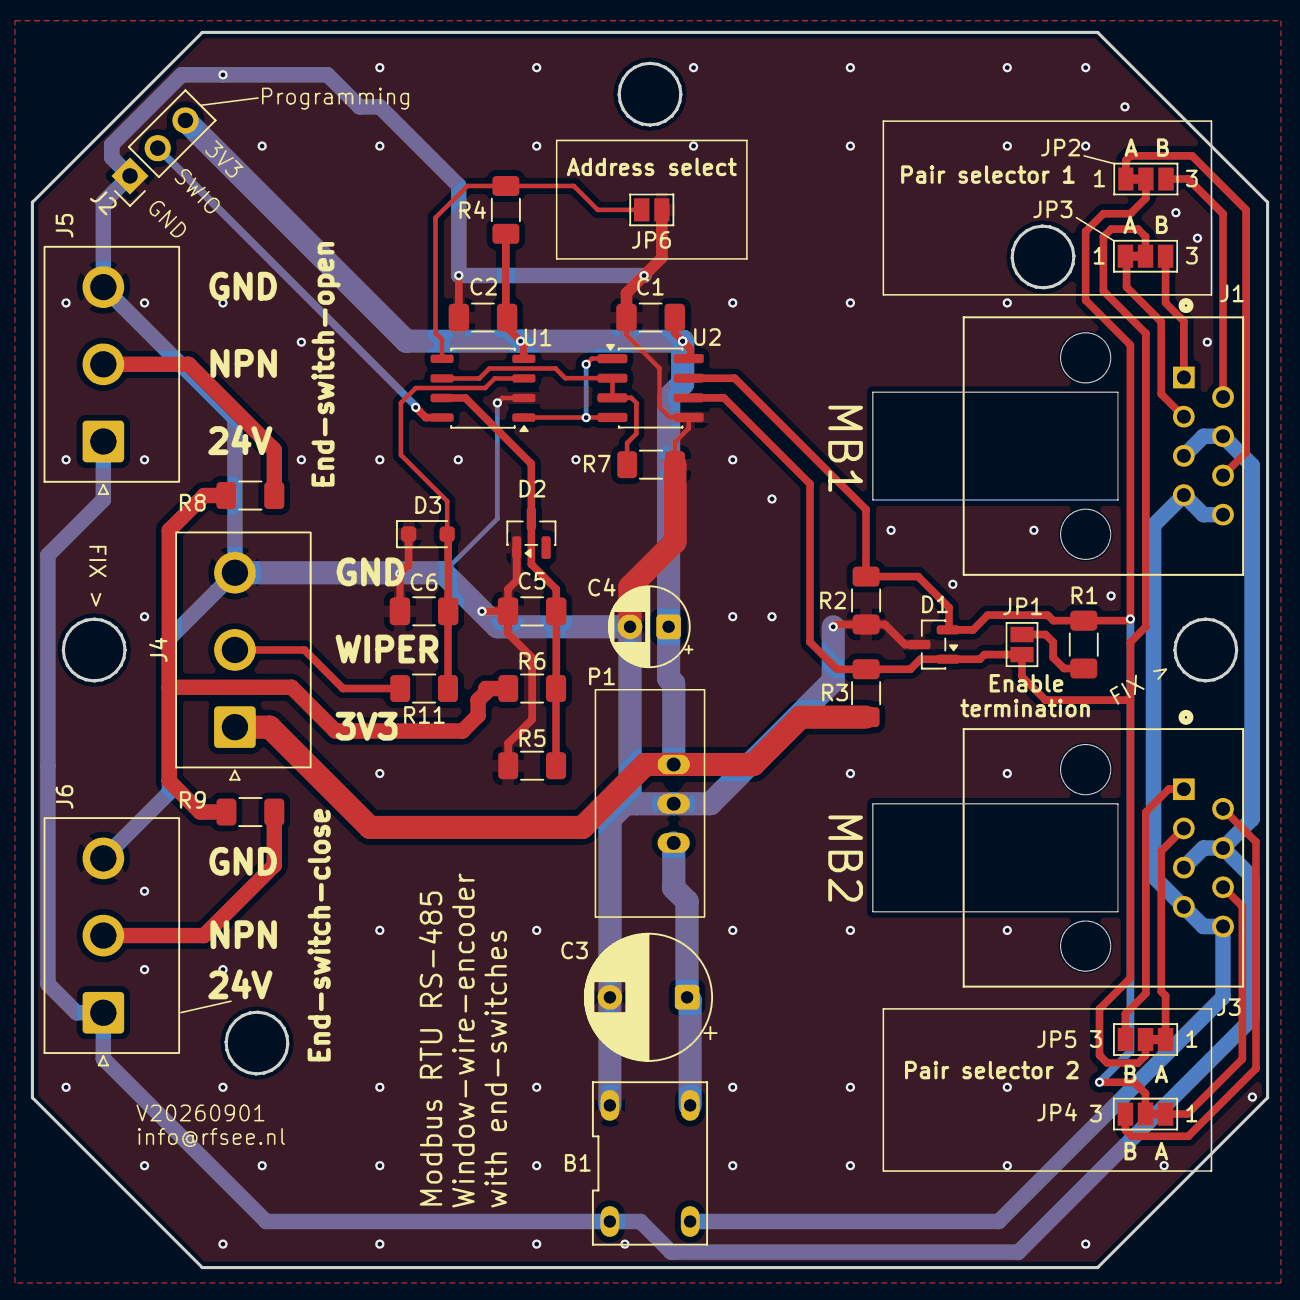
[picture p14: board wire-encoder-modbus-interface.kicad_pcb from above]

Board: 2 copper layers, 80.0 x 80.0 mm, 35 parts (0 on the bottom side), 26 nets.

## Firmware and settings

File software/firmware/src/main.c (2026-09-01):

/*
 * Wire encoder Modbus interface — product firmware (CH32V003J4M6, SOIC-8)
 *
 * Measures how far a window is open. A draw-wire encoder attached to the moving
 * frame turns a 10 kΩ potentiometer; the wiper is read ratiometrically on PA2
 * and published over Modbus RTU (TDS §1.1, §3.4).
 *
 * Zero-ISR cooperative super-loop (design/softwareArchitecture.md).
 * Stage D state (design/integrationPlan.md): board bring-up, the register image
 * (regs.c), flash persistence, the encoder driver (we.c) and the measurement
 * service (meas_open.c) are all in place, so 30001/30005/30012/30015 and status
 * bits 2/3/4 are live. Still missing is stage E — the averaging engine — so
 * 30002 (mean) and 30003/30004 (window min/max) do not yet update and status
 * bit 1 stays set.
 *
 * Assumed pin map (TDS §4.2 — no schematic exists yet): PD6 Modbus line
 * (remap-switching discipline, no HDSEL), PA2 potentiometer wiper (ADC ch0),
 * PC2 DE/R̄Ē, PC1 address jumper, PC4 end-switch divider (ADC ch2), PD1 SWIO.
 * Every pin is committed; PC1/PC4 are assigned the reverse of the obvious way
 * because PC4 has an ADC channel and the switch divider needs it.
 */

#include "board.h"
#include "ch32fun.h"
#include "mb.h"
#include "meas_open.h"
#include "regs.h"
#include "sensors.h"
#include "we.h"

int main(void)
{
	SystemInit();
	funGpioInitAll();

	/* FR-S18 init order:
	 * (1) PC2/DE low first + (2) PC1 address latch + IWDG + PVD ... */
	board_init_early();

	/* FR-S18 (3): sensor front-end ready. Before regs_init, so the ADC
	 * self-calibration is complete before anything can read a register. */
	we_init();

	/* regs_init loads the persisted holdings (FR-S39) BEFORE the measurement
	 * service latches the window, so the first window already uses the stored
	 * duration — no spurious first-window abort at boot. */
	regs_init(board_mb_address());

	/* The measurement service latches 40002 AFTER regs_init has loaded the
	 * persisted holdings, so the first window already runs at the stored
	 * duration and does not abort itself on the first pass (FR-S30). */
	meas_open_init();

	/* (4) USART receiver enabled last. */
	mb_init(regs_cfg());

	const uint32_t second_ticks = FUNCONF_SYSTEM_CORE_CLOCK;
	uint32_t t_second = SysTick->CNT;

	while (1)
	{
		mb_poll();
		regs_service();          /* FR-S30/FR-E05: config change -> clear */
		regs_persist_service();  /* FR-S39: save changed settings to flash
		                          * (after mb_poll sent any response) */

		/* Window pacing, wiper and ladder sampling, FR-E04 scaling and
		 * publication. Placed after regs_persist_service so a flash write
		 * never sits between a sample and its publication. */
		meas_open_service();

		if ((uint32_t)(SysTick->CNT - t_second) >= second_ticks)
		{
			t_second += second_ticks;
			regs_second_tick();
		}

#ifdef TEST_HOOKS
		if (regs_test_hang_requested())
			for (;;)
				; /* FR-S20 test: stop servicing AND feeding — dog bites */
#endif
		/* FR-S20: refresh only here, at the end of a full loop pass, and
		 * only while the rail is healthy (FR-S22). */
		if (board_power_ok())
			board_iwdg_feed();
	}
}

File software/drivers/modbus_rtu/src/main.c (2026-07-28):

#include "ch32fun.h"
#include "mb.h"

// Modbus RTU driver HIL test shell — TTL-level rig (no MAX3485 yet).
//
// NO debug UART here: PD6 IS the bus (FR-S19 — never transmit except in
// response to a valid addressed request). Observability = the bus itself,
// decoded on the Saleae; DE on PC2 is observable on a second channel.
//
// Slave address 40 (TDS FR-S03 jumper-open value; the PC1 jumper itself is
// handled at integration). Holding registers mirror TDS §2.8; input
// registers serve known patterns for read/byte-order tests plus live uptime
// and the driver's own diagnostic counters, so the protocol matrix can run
// long before the measurement path exists.

static uint16_t h_offset = 0;      // 40001 zero offset: 0..65534, default 0
static uint16_t h_window = 1000;   // 40002 meas. window: 100..60000, def 1000
static uint16_t h_avg = 10;        // 40003 averaging: 1..600, def 10 (FR-S31)
static uint16_t h_travel = 10000;  // 40004 full travel: 1..65534, def 10000
static uint16_t h_raw_closed = 0;  // 40005 raw @ closed: 0..65534 (FR-E06)
static uint16_t h_raw_open = 1023; // 40006 raw @ open:   1..65535 (FR-E06)

static const mb_holding_t holdings[] = {
	{0x0000, 0, 65534, &h_offset},
	{0x0001, 100, 60000, &h_window},
	{0x0002, 1, 600, &h_avg},
	{0x0003, 1, 65534, &h_travel},
	{0x0004, 0, 65534, &h_raw_closed},
	{0x0005, 1, 65535, &h_raw_open},
};

static volatile uint32_t uptime_s;

// FR-S31: (averaging window x 1000) >= measurement window, and FR-E06:
// raw_open > raw_closed. Both evaluated against the staged pair (falling
// back to current values where not staged), so an FC16 that moves both
// halves of a constraint at once is judged on its result (FR-MB22).
static bool cross_validate(const uint16_t *addrs, const uint16_t *vals,
                           uint8_t n)
{
	uint16_t window = h_window;
	uint16_t avg = h_avg;
	uint16_t raw_closed = h_raw_closed;
	uint16_t raw_open = h_raw_open;
	for (uint8_t i = 0; i < n; i++) {
		if (addrs[i] == 0x0001)
			window = vals[i];
		if (addrs[i] == 0x0002)
			avg = vals[i];
		if (addrs[i] == 0x0004)
			raw_closed = vals[i];
		if (addrs[i] == 0x0005)
			raw_open = vals[i];
	}
	return (uint32_t)avg * 1000u >= window && raw_open > raw_closed;
}

static uint16_t input_read(uint16_t addr, bool *ok)
{
	switch (addr) {
	case 0x0000: return 1234;          // fixed pattern
	case 0x0001: return 250;           // fixed pattern
	case 0x0002: return 900;           // 0x0384 — byte-order probe (FR-MB25)
	case 0x0003: return 0;
	case 0x0004: return 511;
	case 0x0005: return 3;             // synthetic status bits
	case 0x0006: return 0x0107;        // build/version pattern (FR-S32 shape)
	case 0x0007: return (uint16_t)uptime_s;
	case 0x0008: return mb_crc_error_count();
	case 0x0009: return mb_served_count();
	case 0x000A: return 42;
	case 0x000B: return 80;
	case 0x000C: return mb_fe_count();
	case 0x000D: return mb_ne_count();
	case 0x000E: return mb_ore_count();
	case 0x0010: return mb_last_bad(0);
	case 0x0011: return mb_last_bad(1);
	case 0x0012: return mb_last_bad(2);
	case 0x0013: return mb_last_bad(3);
	default:
		*ok = false;
		return 0;
	}
}

static const mb_config_t cfg = {
	.address = 40,
	.holdings = holdings,
	.n_holdings = sizeof(holdings) / sizeof(holdings[0]),
	.input_read = input_read,
	.cross_validate = cross_validate,
};

int main()
{
	SystemInit();
	funGpioInitAll();
	mb_init(&cfg);

	const uint32_t second_ticks = FUNCONF_SYSTEM_CORE_CLOCK;
	uint32_t t0 = SysTick->CNT;

	while (1)
	{
		mb_poll();
		if ((uint32_t)(SysTick->CNT - t0) >= second_ticks)
		{
			t0 += second_ticks;
			uptime_s++;
		}
	}
}

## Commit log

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2026-07-28 TDS v0.4: direction-agnostic scaling, max-age contract, enclosure spec
    Direction of travel (was a live 50/50 risk once the M3 mechanism was known —
    raised to close, lowered to open, so the wiper sense depends entirely on how
    the draw-wire is fitted):
    - FR-E04 now accepts the two calibration points in either order. A mounting
    where the wiper code falls as the window opens calibrates exactly like a
    normal one: no invert register, no extra installer step, no wire to swap.
    - FR-E06 changed from an ordering constraint to a distance one, plus a
    minimum span of 64 counts. Two near-adjacent codes previously passed "not
    equal" while letting one LSB of ADC noise swing the full travel. The s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
    [board.c, main.c, regs.c]
2026-07-29 git commit -F- <<'MSG' Redesign the end-switch interface as an attenuating divider
    The LJ18A3-8-Z/BX output is not a bare open collector. LJ_en.pdf p.2 shows an
    internal 10k pull-up to +V, so an inactive sensor SOURCES 24 V rather than
    floating. The previous topology assumed it floated and pulled the line up to
    3.3 V itself, which would have put 10.4 V on PC4 with one sensor inactive and
    14.0 V with both, against an ADC pin whose maximum is a diode drop above
    3.3 V. That is a destroy-the-part error, caught before any board existed.
    The sensor already delivers a clean 0-24 V signal behind a known impedance, so
    the board now attenuates and clamps instead of exciting:
    field junction 470k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
    [regs.c]
2026-07-29 Move supplier images to a subfolder, rename and index them
    documentation/ held 14 loose product images with opaque hash filenames, only
    one of them indexed - and that one described wrongly. They are now in
    documentation/product-images/ with descriptive names and their own readme.
    All 13 are tracked as pure renames.
    Removed documentation/S4a98f76ed9f049c3ac94bcd5a02d4304h.avif: byte-identical
    (same SHA-256) to S27400dc13c7f47c89c9d11c40bc4700bd.avif, now
    drawwire-specification-table.avif. Recoverable from history if wanted. That
    duplicate is also what exposed the mis-index - it was described as a product
    image for the ZY encoder catalogue when it is in fact the draw-wire
    specification table.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
2026-07-29 Add FR-E18 endpoint capture and FR-E19 commanded teach
    The end switches are the only independent physical reference this device has.
    A draw-wire that has slipped on its drum reports a plausible, stable, wrong
    opening and nothing in the wiper path can tell - which is exactly the
    mechanical drift the greenhouse study fitted a sensor to catch (its 1.2, and
    AT-WP09). At the moment a stop is reached the true position is known, so the
    raw code read then IS that endpoint. That turns the switches from a bit you
    can read into a measurement of how far the calibration has drifted, against a
    physical stop rather than against anyone's travel-time model.
    FR-E18 - report. Every debounced transition into "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
    [regs.c]
2026-07-29 Settle the enclosure at IP65 and close the compliance gaps
    NFR-ENV03 said IP67; the selected Kopp 99966478 is IP65. Narrow the
    requirement to what the bill of materials delivers and name the box as
    what sets it — the same treatment the +65 C ceiling got from the LJ18A3.
    IP65 is the greenhouse study's stated minimum; its IP67 preference was
    written for hardware at the aperture, and this box holds only the
    electronics. The TDS SS6 open item becomes a decision.
    requirementsCompliance.md SS4 was stale. Both gaps it originally raised
    are closed by the draw-wire supplier specification: >100 000 cycles
    against NF-WP08, and 0.2 % comprehensive error against FR-WP05/06.
    Three gaps replace them, tw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
    [regs.c, test_scale.c]
2026-08-06 Add a KiCad .gitignore for the flattened project layout
    The project files now sit directly in hardware/KiCad/ alongside the
    my-KiCad-library and wch_kicad_library submodules, so ${KIPRJMOD}
    resolves to that directory and fp-lib-table/sym-lib-table load the
    submodules themselves instead of local copies. This settles the
    divergence noted earlier: there is now one source of truth for the
    libraries.
    The .gitignore is scoped to hardware/KiCad rather than added to the
    root, so it travels if the project is ever copied out on its own --
    which is how KiCad projects usually move. It covers session state,
    locks, autosave and backups, rescue libraries, fabrication output, and
    board-level 3D and PDF exp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
    [pcbOutline_001.skp]
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2026-08-07 Point the library submodule at master, which has the missing parts
    The submodule was pinned to fdb4bd7 on main, whose my-KiCad-library.kicad_sym
    carries 22 symbols and lacks both DB207 and HLK-K7803-500R3. Its .pretty
    directory lacks the DB207-DIP-4 and HLK-K7803-500R3 footprints as well. The
    schematic and board opened regardless, because KiCad caches symbol and
    footprint definitions inline in the .kicad_sch and .kicad_pcb -- so the gap
    was invisible until Update Symbols from Library, and a fresh clone would have
    got a design whose bridge rectifier and buck regulator could not be resolved
    from any library.
    master at 1ebcfbc has all four, committed and pushed. The move is purely
    additive: gi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
    [pcbOutline_001.skp, wire-encoder-modbus-interface.kicad_pcb]
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2026-08-08 Specify the window emulator, and accept its relay realisation
    A bench rig standing in for a window and its actuator controller: a
    carriage on a linear axis, two potential-free contact inputs, and end
    switches that inhibit the command in their own direction. Scoped to the
    rig alone -- it specifies nothing about what is mounted on it.
    SS2 records the control logic and its truth table, with the completeness
    check (four inputs, sixteen combinations, six rows covering
    4+2+2+2+2+4) and the Boolean reduction. The don't-cares are genuine:
    only the end switch in the direction of travel may inhibit, so CloseEnd
    is correctly ignored while opening.
    SS3 is the accepted realisation -- two DPDT relays as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
2026-08-31 Measure the switch bands, correct a stale proof, write the test plan
    Three strands, all following from hardware existing for the first time.
    MEASURED, not computed. All three switch states read on the bench, and
    the fitted model agrees to <=0.1 mV: neither 0.329 V (102), one active
    1.502 V (466), both active 2.320 V (720). Two unknowns resolved in
    opposite directions. The output drop is ZERO at this network's 290 uA --
    Von = 24.04 V against a 24.04 V supply -- so the datasheet's <=2.5 V, a
    300 mA figure, does not apply, and the SS6 blocker closes. Confirmed
    twice independently, the second time from both-active, which carries no
    leakage term and still lands on 24.04 V.
    But the off-state lea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
    [sensorArm_001.skp, sensorArm_001.stl, sensorSupport_001.skp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]
2026-08-31 Re-measure the switch bands on a corrected rig
    TP-A00 found two faults on the breadboard before any reading could be
    trusted: R10 was still fitted, and R5 was floating. That bench was
    neither the schematic nor a divider, and every switch measurement taken
    earlier today was of a circuit that did not exist. All of it is
    discarded. The rig-check row earned its place on first use.
    Re-measured with R10 out and the divider intact, at Von = 23.82 V:
    neither active 0.310 V 96 counts
    one active 1.481 V 460 counts (open 1.477, close 1.485)
    both active 2.300 V 714 counts
    The model reproduces all three to <=1 mV, and Von is confirmed three
    times independently -- from each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
    [regs.c]
2026-08-31 Measure the switch bands on a clean bench, and retract two findings
    Fourth measurement set of the day and the first trustworthy one. The
    earlier three were taken on a bench that variously had R10 fitted, R5
    floating, another wiring error, and -- the one that survived every rig
    fix -- the MCU's internal pull-up on PC4. Each produced a plausible fit.
    All three are discarded.
    Measured at Von = 23.09 V against a 24.1 V rail, with Von confirmed by
    three independent routes agreeing to 0.2 % -- each switch alone, and both
    together, which carries no leakage term at all:
    neither active -0.019 V 0 counts
    one active 1.291 V 401 counts
    both active 2.210 V 686 counts
    Two r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
    [regs.c]
2026-09-01 Add a gotcha log, and record the first hardware test results
    docs/gotcha-log.md collects what went wrong on this project and why.
    Most of it is invisible afterwards -- a corrected schematic looks exactly
    like one that was never wrong -- so the log exists to keep the cost of
    those hours from being paid twice. Five entries, all from the first bench
    day, and two promoted patterns: suspect the rig before refitting a model,
    and verify hand-edited KiCad by netlist diff. Linked from contributing.md
    and added to the Doxygen input.
    software/hil/testReport.md was materially false. It still claimed no
    hardware existed and that nothing had been run, while the bench had
    verified the debug link, flashed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
2026-09-01 Add a raw M2K Modbus master, and host-test the protocol half of it
    Group B's 24 protocol rows were blocked on having no Modbus master. This
    supplies one: a second MAX3485 bit-banged from M2K digital I/O. That is
    better than a USB adapter here rather than a substitute for one --
    FR-MB20/21/23 are timing requirements, and an adapter hides inter-frame
    timing behind its own driver's buffering. Every bit is placed
    deliberately.
    Split in two, for the same reason scale.c is split from the firmware.
    modbus_rtu_codec.py holds framing, CRC-16 and the 8N1 bit codec in pure
    Python with no instrument dependency, so the parts most likely to be
    subtly wrong can be proven before anything is plugged in. A f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
2026-09-01 Fix the selftest's released check, and log the stale-buffer trap
    The selftest reported that the master's RS-485 driver would not release
    the bus -- `released` measured identical to `drive mark`. An hour went
    into hunting a wiring fault that did not exist: continuity checks, bias
    resistors, powering the master's transceiver down to identify which end
    was driving, and a 20-cycle intermittency test that came back 20/20 good
    and was therefore disbelieved.
    libm2k's analog input is buffered, and the first getSamples() after a
    state change returns the buffer already in flight -- so one read per
    state reports the PREVIOUS state. The selftest read once; the ad-hoc
    diagnostics happened to read two or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
2026-09-01 Bring the Modbus link up, and fix a UART decoder that could not hold sync
    The DUT answers. First transaction reads 30007 = 0x0101 (build 0x01,
    firmware 1) and a full 15-register FC04 block.
    Three faults stood in the way, none of them in the firmware:
    * No RS-485 fail-safe bias. Idle differential was -11 mV where a
    receiver needs 200 mV, so the DUT's RX input had no defined state.
    A ~120 ohm termination was present and 20k bias could not pull
    against it. Fixed on the bench: termination out, 680 ohm bias,
    idle now +258 mV.
    * A leading null on every reply, from RO floating while the master
    transmits (DE and RE tied). The master now locates the span that
    starts with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
2026-09-01 Run Group B against the DUT, and correct the plan's Modbus tracing
    33 checks pass, 0 fail across 19 protocol and lifecycle rows, driven by the
    M2K raw master against the encoder build at unit 40.
    What the DUT got right: exception codes 01/02/03 and nothing else;
    out-of-range writes rejected rather than clamped, with the register
    provably unchanged; FC16 atomic, no partial writes; reads spanning the
    map edge rejected whole; FC06 responses byte-identical to the request and
    FC16 responses carrying address and quantity rather than data; frames
    below t3.5 merged and discarded, frames above it split and served.
    FR-MB06's deliberate deviation holds: broadcast writes are ignored, not
    executed. The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
2026-09-01 Measure response latency against DE, and correct 53 wrong dates
    TP-B14/TP-B29 (FR-MB20/FR-MB21) now PASS on measured evidence: n=1000,
    median 4.08 ms, p95 4.13 ms, max 4.14 ms against a 100 ms limit, 100 %
    within the 15 ms FR-MB21 prefers, none unanswered.
    An earlier figure of 11.85 ms is RETRACTED. It located the end of our own
    frame from the RX line, which assumes our transmission appears on RO. It
    does not -- RE is tied to DE, so the DUT's receiver is disabled while we
    transmit and the first edge in the capture is RO's enable transient.
    Every sample was measured from an origin ~70 bit times adrift.
    Latency is now timed against DE, which we drive and which the M2K
    captures on the same ti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
    [regs.c]
2026-09-01 Measure DUT DE timing from the bus envelope, and retract a false FAIL
    TP-B32 (FR-MB04) PASSES: DE asserted 3-82 us before the first start bit
    and released 3-6 us after the last stop bit, against a one-character
    budget of 1146 us. n=10.
    Measured from the bus rather than from PC2. The DUT drives only while its
    DE is asserted, so the drive envelope is on the M2K analog inputs on the
    same timebase as the data -- driven is +/-1.4 V, released is the 0.26 V
    fail-safe bias. No second probe, no second instrument's clock.
    An earlier FAIL on this row is RETRACTED. It was an analysis error, not a
    DUT defect. The differential passes through zero at every bit transition,
    so thresholding on |A-B| and req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
2026-09-01 Close six Group B rows: watchdog, DE timing, address jumper, persistence
    58 checks passing, 0 failing.
    TP-B21 (FR-S20): magic 0xDEAD to holding 0x00FF stopped the main loop
    refreshing the IWDG; the device answered a valid FC04 again 1.20 s later
    with no power cycle, against a 3 s budget. The row first proves the device
    actually stopped answering -- without that, a watchdog that never fired
    and a device that never hung look identical.
    TP-B22 (FR-S21): six post-reset checks after BOTH reset causes this bench
    can produce, the watchdog and a true power-on. Different paths through the
    firmware; passing one does not imply the other.
    TP-B02: complete on all three clauses. Bridged -> answers at 4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
2026-09-01 Close TP-B24 and TP-A09; leave TP-B35 undetermined pending a rerun
    TP-B24 (FR-S19) PASSES on the third attempt. With the master held
    released and sending nothing for 120 s spanning a full power cycle, the
    bus never left the fail-safe bias -- peak 0.296 V against a 0.26 V bias
    and a 1.4 V driven level. No boot banner, no test bytes.
    The first two attempts reported INCONCLUSIVE, not PASS: uptime went
    491->538 and 562->683, so no reset fell inside either window and nothing
    was tested. The row refuses a verdict until uptime has gone backwards.
    This time it went 29136 -> 106. Without that guard two empty runs would
    have been written up as clean passes.
    Recorded as a pass WITH SCOPE, not a close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
2026-09-01 Close TP-B35: 10 000 cycles clean, and the FAIL was my classifier
    FR-S16 (internal 48 MHz HSI, no crystal) and FR-MB23 (RX discarded while
    transmitting) both PASS over the full 10 000 request/response cycles the
    requirement specifies. 30009 moved by 0, 30010 by exactly 10 000, latency
    median 4.08 ms and max 4.14 ms over 9998 samples. The verdict rests on the
    DUT's own counters, not on what the script believes it sent.
    An earlier run reported FAIL on 4 of 8 master-side misses attributed to
    the DUT's transmit clock. That attribution was mine and it was wrong: the
    classifier counted any capture containing edges as implicating the DUT,
    but a TRUNCATED capture also has edges and also will not de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
2026-09-01 Accept TP-B20 at 13 cycles, and promote the session's recurring test bug
    TP-B20 (FR-S39) ACCEPTED at 13 of 20 cycles, no corruption in any. The
    remaining seven were dropped by decision, not overlooked: each costs ~200
    flash writes and the run had already spent ~23 % of a conservative 10k
    endurance budget on this prototype. Recorded in both the plan and the
    report as a decision with its reason, and flagged to be re-run in full on
    the PCB where the flash is not a hand-built board's.
    Bench restored: section 2.8 defaults written back and verified by
    read-back, release build at address 40, 30007 = 0x0101.
    PROMOTED PATTERN: a test that blames the device must first rule out the
    instrument. This h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
2026-09-01 Act on three decisions: delete TP-B03, drop FR-MB28's dead clause, mark the test build
    1. TP-B03 DELETED. It measured boot time against FR-S02, which says 'a
    single hardware PCB shall support the device without modification' and
    defines no budget. No boot-time requirement exists anywhere in the TDS,
    so the row had no pass criterion to measure against.
    Deleting it exposed that FR-S02 then had no test at all -- the row had
    been occupying its citation while testing something else entirely. Added
    TP-B36 for what FR-S02 actually requires: the release binary on an
    unmodified PCB, no cuts or bodges, passing the full section 2/3 suite.
    BLOCKED, since no PCB exists yet.
    2. F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
2026-09-01 Implement the wire-encoder ADC driver, and correct a stale API contract
    we.c: the driver everything downstream was blocked on. we.h had been an
    API contract with no implementation since July, and integration stage D
    cannot start without it.
    we_init PA2 (ch0, wiper) and PC4 (ch2, end-switch divider) as
    analog with NO pull; ADC at HCLK/8 = 6 MHz; 73-cycle
    sample time on both channels; RSTCAL then CAL before any
    conversion, which is what FR-S18 step 3 exists to order.
    we_sample FR-E07 integrity check, then 16 conversions with the
    extreme pair discarded and the middle 14 meaned. FR-E13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
    [wire-encoder-modbus-interface.kicad_pcb]
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2026-09-01 Verify FR-E07 on hardware, both directions
    PASS, measured across real transitions with the wiper physically
    disconnected and reconnected:
    reconnect bit 2 clears, 30001 returns to 6647, 30011 resets to 0
    disconnect 30001-30004 -> 65535, bit 2 set, 30011 = 3 s
    budget 3.4 s = 2 s timer + two 200 ms windows + 1 s granularity
    30005 holds 679/681 through the fault -- the last code the
    front-end produced, retained as a diagnostic
    It RECOVERS. A machine that latched permanently would be
    indistinguishable from this one in steady state; only the reconnect
    separates them.
    The number is coherent rather than merely inside a limit. At a 1000 ms
    window the same measur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
2026-09-01 Integration stage F: acceptance suite green, 8 passed
    software/hil/acceptance/ run against the flashed release build:
    8 passed, 0 failed, 2 min 7 s.
    THE TRACEABILITY GATE IS A TEST, NOT A DOCUMENT. NFR-TST01's criterion is
    not 'the tests pass' -- it is that the report lists every non-excepted
    active FR-MB ID with result PASS, and a MISSING id blocks a release
    exactly as a failing one does. So the gate re-reads the TDS at run time,
    enumerates the FR-MB ids that exist, and fails if any is unaccounted for.
    Adding a requirement now breaks the suite until it is covered or
    excepted. It fails the other way too: a map entry naming a requirement
    the TDS no longer defines is a coverage claim for some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
2026-09-01 Run Group C, and fix an FR-E12 violation in the driver I wrote
    Group C: 11 pass, 0 fail. Most of Group C needs the window to MOVE, which
    this bench cannot do, but FR-E04 is a pure function of the raw code and
    the three calibration registers -- so driving the CALIBRATION against a
    fixed wiper exercises the whole path end to end against a prediction
    computed independently in the test. Every case matched exactly:
    nominal 673 -> 6578 offset at closed 673 -> 7078
    travel doubled 673 -> 13157 REVERSED mounting 673 -> 3424
    narrow span 673 -> 7300 below closed pt 673 -> 0
    above open point 673 -> 10000
    Plus FR-S24 (30001 is the scaling of the SAME respon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
2026-09-01 Curate: 3 gotchas, 1 promoted pattern, and 11 undocumented scripts
    Freshness: MEMORY.md carried a false state claim -- 'Stage D not started'
    and 'next: the M2K raw-master scripts' -- when stages A-F are complete.
    Rewritten with a verify comment pointing at integrationPlan.md's Status
    row, which is updated in the same commit as the work.
    New gotchas:
    * A driver written to a stale header comment. we.c used 73 ADC sample
    cycles where FR-E12 requires >=241, because we.h still said '>=71' --
    the value FR-E12 explicitly supersedes.
    * The blocking budget nobody wrote down. 1.146 ms per main-loop pass,
    absent from every requirement, failing silently as dropped frames
    with 30009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
2026-09-01 Close four movement rows with the window emulator
    The rig from design/windowEmulator.md is built. One hand-driven traverse
    closed four requirements blocked since integration stage D.
    The traverse: closed stop 30005 = 0 / 30001 = 0; open stop 30005 = 1022 /
    30001 = 9990 (999.0 mm), bit 3 set at both. The wiper spans essentially
    the whole 10-bit range against the DEFAULT calibration (40005 = 0,
    40006 = 1023) -- one count short at the top. The front-end and the
    register defaults agree with no adjustment.
    FR-E10 PASS 30012 both signs (+1095 opening, -1378 closing) and the
    sign agreed with the direction of change in 604 of 604
    steps
    FR-E14 PASS bit 3 set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
2026-09-01 Verify FR-E18/FR-E19 teach handshake, and find an EM-M05 rig issue
    7 pass, 0 fail. Every clause of FR-E19 in order:
    (a) arm 40007=1 sets status bit 5
    (a) stale discarded reading pre-existing 30013/30014 (22, 910)
    after arming committed NOTHING
    (b) capture at each stop 2 entries, closed at -919, open at +890
    (c) commit WAITS bit 5 still set after both captures, before
    they were read
    (c) commit 40005=56, 40006=834, bit 5 clear, 40007=0
    FR-E18 direction closed took the lower code (56 < 834)
    (d) abort 40007=0 clears bit 5, calibration untouched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
2026-09-02 Retract a rig finding, prove EM-M05 and FR-E01, correct FR-E03's scope
    Four things, none of which stand alone.
    RETRACTED: the teach commit claimed the closed-end sensor violated EM-M05
    and recommended moving both sensors. Wrong on three counts. Actuating
    BEFORE the mechanical limit is the design -- EM-M03 requires a hard limit
    beyond each actuation point, and in service the drive is inhibited at the
    switch, so the switch point IS the operational end of travel. So the
    taught calibration (40005=56 / 40006=834) is right, not narrow. And the
    evidence never said what was claimed: the movement log shows bit 3 held
    for 20 SECONDS at raw 0. A rig fault was built from a one-sample
    ambiguity and a ha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
2026-09-02 Step 2: implement FR-E23 and FR-E24 in health.c, with 25 host tests
    New health.c / health.h, factored out of regs.c the way scale.c and avg.c
    are -- pure logic, no hardware, no SysTick, time counted in measurement
    windows supplied by the caller. That is what makes test_health.c able to
    prove it on the host before any hardware sees it.
    FR-E24 (bit 6): raw outside [40005 - M, 40006 + M], M = span/4,
    persisting >= 2 windows. Handles a reversed calibration (40006 < 40005)
    by taking the span as a magnitude, and SATURATES the low edge at 0 rather
    than underflowing -- an unsigned wrap there would invert the band and
    report every code as implausible, a firmware bug that looks exactly like
    a field f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
    [regs.c]
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
